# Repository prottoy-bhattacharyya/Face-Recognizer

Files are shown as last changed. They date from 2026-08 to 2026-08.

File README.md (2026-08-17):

# Smart Room & Gate Access Control System

A face-recognition-based IoT access control and room automation system. The project combines an ESP32-CAM, two ESP8266 microcontrollers, and a Django backend running YOLOv8 + DeepFace to let users unlock a gate with their face (or a PIN fallback) and remotely control room fan and lighting — with admin-only controls over face enrollment and the gate password.






---

## Table of Contents

- [Overview](#overview)
- [System Architecture](#system-architecture)
- [Hardware Components](#hardware-components)
- [Features](#features)
- [User Roles](#user-roles)
- [Getting Started](#getting-started)
  - [Backend (Django) Setup](#backend-django-setup)
  - [Firmware Setup](#firmware-setup)
- [API Reference](#api-reference)
  - [Django Server Endpoints](#django-server-endpoints)
  - [ESP8266 #2 (Room Automation) Endpoints](#esp8266-2-room-automation-endpoints)
- [Access Control Flow](#access-control-flow)
- [Web & Android Apps](#web--android-apps)
- [Roadmap / Known Limitations](#roadmap--known-limitations)
- [License](#license)

---

## Overview

The system is built around three microcontroller-class devices and a central Django server:

- **ESP32-CAM** — streams live video used for face capture.
- **ESP8266 #1 (Access Control Unit)** — keypad + OLED display; triggers face verification and handles PIN fallback.
- **ESP8266 #2 (Room Automation Unit)** — drives the gate servo, fan servo, room LEDs, and reads a DHT11 temperature/humidity sensor.
- **Django backend** — performs face detection (YOLOv8) and face matching (DeepFace), manages user accounts, and exposes a REST API consumed by both microcontrollers and the web/Android apps.

## System Architecture

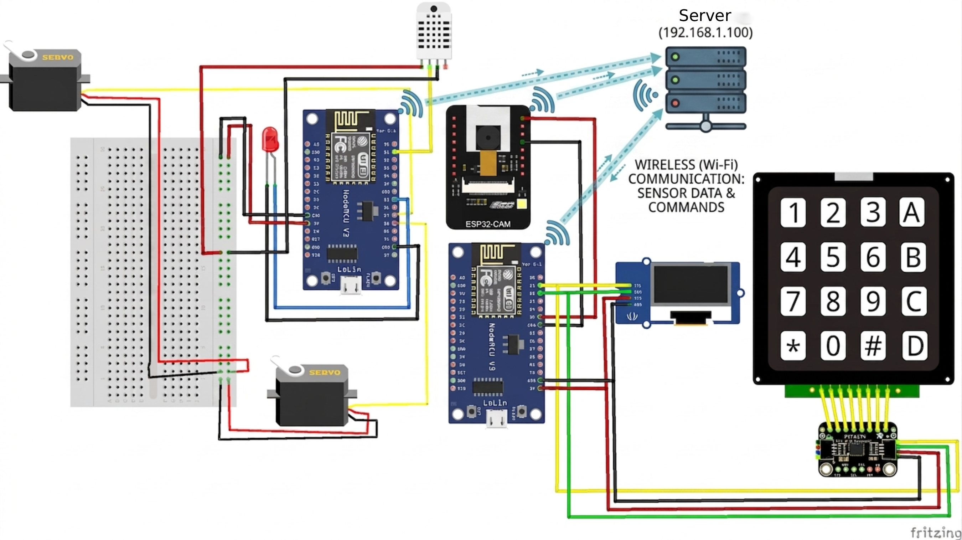
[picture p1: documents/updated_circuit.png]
Circuit Diagram


- **Security loop:** camera → server → ESP8266 #1 → ESP8266 #2, gated by face or PIN verification.
- **Convenience loop:** web/Android app talks directly to ESP8266 #2 for fan and light control, bypassing the server.

## Hardware Components

| Component | Role |
| --- | --- |
| ESP32-CAM | Captures and streams live video frames for face detection and enrollment |
| ESP8266 #1 (Access Control)  | Keypad + OLED interface; authenticates with Django, triggers face verification, handles PIN fallback |
| ESP8266 #2 (Room Automation) | Local web server exposing gate, fan, light, and sensor control endpoints |
| 4x4 Matrix Keypad + PCF8574  | Manual PIN entry via I2C GPIO expansion |
| SSD1306 OLED Display | Shows system status, verification results, and PIN entry feedback |
| DHT11 Sensor | Room temperature and humidity for automatic fan control |
| Gate Servo | Actuates the gate lock/latch mechanism |
| Fan Servo | Drives the fan on/off actuator |
| Blue / Yellow LEDs | Room light ON/OFF indicators |

## Features

- 🎯 **Face-recognition gate entry** using YOLOv8 for detection and DeepFace for matching
- 🔢 **PIN fallback** via a physical keypad if face verification fails
- 🌡️ **Automatic fan control** based on a configurable temperature threshold (with hysteresis)
- 💡 **Remote light and fan control** from a web dashboard and Android app
- 🚪 **Auto-closing gate** (5-second timer) with no separate close request needed
- 🔐 **Role-based access** — only the admin account can enroll/delete faces or change the gate password
- 📶 **Session-based authentication** shared between the Django server and both ESP8266 units

## User Roles

| Capability | Admin Account |  Regular User |
| --- | :---: | :---: |
| Open gate via face recognition | ✅ | ✅ |
| Open gate via keypad PIN | ✅ | ✅ (shared PIN) |
| Control fan / light (web & Android) | ✅ | ✅ |
| Enroll a new face | ✅ | ❌ |
| Delete a face / reset database | ✅ | ❌ |
| Update the gate password | ✅ | ❌ |

## Getting Started

### Backend (Django) Setup

**Requirements:** Python 3.9+, MySQL/MariaDB (or your configured DB), a webcam-compatible MJPEG stream URL.

```bash
# Clone the repository
git clone https://github.com/<your-username>/<your-repo>.git
cd <your-repo>/server

# install uv
pip install uv
```

Configure your database and camera settings (e.g. in `settings.py` or a `.env` file):

```python
CAMERA_URL = "http://<esp32-cam-ip>"
CONTROL_SERVER_URL = "http://<esp8266-2-ip>/"
```

Run database migrations and start the server:

```bash
python -m uv run manage.py migrate
python -m uv run manage.py runserver 0.0.0.0:8000
```

The YOLOv8 face model (`yolov8n-face.pt`) is loaded automatically from the `models/` directory on first run.

### Firmware Setup

Both ESP8266 sketches are written for the **Arduino IDE** (or PlatformIO) targeting the ESP8266 board package.

1. Install required libraries: `ESP8266WiFi`, `ESP8266HTTPClient`, `ESP8266WebServer`, `ArduinoJson`, `Adafruit_GFX`, `Adafruit_SSD1306`, `I2CKeyPad`, `Servo`, `DHT sensor library`.
2. Update the Wi-Fi credentials and server URLs at the top of each `.ino` file:
   ```cpp
   const char* ssid = "<your-wifi-ssid>";
   const char* password = "<your-wifi-password>";
   String server_url = "http://<django-server-ip>:8000/";
   String second_esp_url = "http://<esp8266-2-ip>/";
   ```
3. Flash `esp8266_access_control` to ESP8266 #1 and `esp8266_room_automation` to ESP8266 #2.
4. Flash the standard ESP32-CAM web server firmware (e.g. `CameraWebServer` example) to the ESP32-CAM, pointed at the same network.

## API Reference

### Django Server Endpoints

| Endpoint | Method | Access | Description |
| --- | --- | --- | --- |
| `/` | GET | Authenticated | Main dashboard |
| `/controls/` | GET | Authenticated | Room controls page (fan/light/gate) |
| `/login/` | GET, POST | Public | Authenticate and start a session |
| `/signup/` | GET, POST | Public | Register a new user account |
| `/logout/` | GET | Authenticated | Flush the current session |
| `/get_updated_password/?username={username}` | GET | Authenticated | Retrieve the current gate PIN |
| `/update_password/` | POST | Admin only | Update the gate password |
| `/faces/{name}/` | POST | Admin only | Capture a frame and enroll a new face |
| `/faces/{name}/` | DELETE | Admin only | Delete a specific user's face data |
| `/faces/` | DELETE | Admin only | Delete **all** enrolled faces |
| `/verify/?threshold={value}` | GET | Authenticated | Capture a frame and match it against enrolled faces |

### ESP8266 #2 (Room Automation) Endpoints

| Endpoint | Method | Description |
| --- | --- | --- |
| `/gate_open` | GET | Opens the gate; auto-closes after 5 seconds |
| `/mode?state={auto\|manual}` | GET | Switches fan control mode |
| `/turn_on_light` | GET | Turns the room light ON |
| `/turn_off_light` | GET | Turns the room light OFF |
| `/fan?state={on\|off}` | GET | Manually sets the fan state |
| `/sensors` | GET | Returns current temperature and humidity |
| `/status` | GET | Returns full system status (mode, light, fan, gate, sensor readings) |

## Access Control Flow

1. ESP8266 #1 logs in to Django on boot and syncs the current gate PIN.
2. Pressing **A** on the keypad triggers `GET /verify/`. On a `"success"` response, ESP8266 #1 calls ESP8266 #2's `/gate_open`.
3. If face verification fails, the user can enter a PIN on the keypad; pressing **#** checks it against the synced PIN and opens the gate on a match.
4. The gate auto-closes 5 seconds after opening — no separate close command is required.

## Web & Android Apps

- **Fan / light / gate control** — sent directly to ESP8266 #2, available to any authenticated user.
- **Face enrollment, face deletion, and gate password updates** — routed through the Django server and restricted to the `admin` account.
- **Face-based gate entry** — available to any enrolled user via `/verify/`.

## Roadmap / Known Limitations

- [ ] Encrypt stored gate passwords instead of plaintext comparison
- [ ] Move hardcoded Wi-Fi/admin credentials in firmware to a config file or provisioning flow
- [ ] Add HTTPS/session hardening between ESP8266 units and the Django server
- [ ] Wire automatic light/fan activation into the gate-open sequence (currently commented out)

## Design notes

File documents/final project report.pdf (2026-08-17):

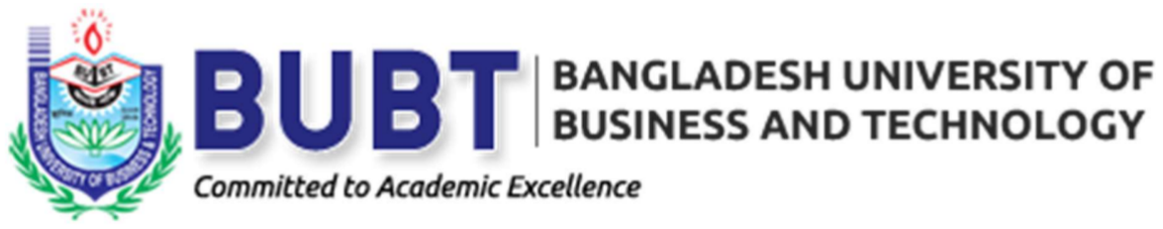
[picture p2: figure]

### BANGLADESH UNIVERSITY OF BUSINESS AND TECHNOLOGY

Department of Computer Science and Engineering

## Design and Implementation of an Edge-IoT and Centralized AI Facial Recognition System for Smart Access Control and Automation

Submitted By

Name | ID

Prottoy Vhattacharyya 20234103430

Chinmoy Roy Dipto | 20234103449
Arifa Islam | 20234103205
Suraiya Rahman Mitu | 20234103215

Submitted To

Ankan Saha
Lecturer
Department of CSE
Bangladesh University of
Business and Technology (BUBT)

Date: August 17, 2026

Smart Room & Gate Access Control System | Project Report

Abstract

This report documents the design and implementation of an IoT-based smart room and gate access control system that combines face recognition, keypad PIN fallback, and remote environmental control. The system integrates an ESP32-CAM for video capture, two ESP8266 microcontrollers for access control and room automation respectively, and a Django backend that performs face detection (YOLOv8) and face recognition (DeepFace). Authorized users can unlock the gate via face verification or a PIN code and control room fan and lighting through companion web and Android applications, while administrative operations such as face enrollment, face deletion, and gate password management are restricted to an admin account.

### Contents

1 Introduction | 3
2 System Architecture | 3
3 Django Server API Endpoints | 6
4 ESP8266 #2 (Room Automation) API Endpoints | 7
5 Access Control Unit (ESP8266 #1) Behaviour | 8
6 Web and Android Applications | 9
7 Conclusion | 9

### 1 Introduction

The Smart Room & Gate Access Control System is an IoT security and automation solution designed to provide contactless, face-recognition-based gate access alongside remote control of room appliances (fan and light). The system is built around three microcontroller-class devices and a central Django server:

- An ESP32-CAM module that streams live video for face capture.
- A primary ESP8266 (Access Control Unit) equipped with a keypad, OLED display, and I/O expander, responsible for triggering face verification and handling PIN-based fallback authentication.
- A secondary ESP8266 (Room Automation Unit) that drives the gate servo, fan servo, room LEDs, and a DHT11 temperature/humidity sensor.
- A Django backend that performs face detection using YOLOv8, face matching using Deep-Face, manages user accounts, and exposes a REST API consumed by both microcontrollers as well as the web and Android applications.

The system supports two classes of users: an admin account with full control over the face database and gate password, and regular users who may open the gate via face verification and operate the fan and light, but cannot enroll or delete faces or change the gate password.

### 2 System Architecture

### 2.1 Circuit Diagram

Figure 1 shows the complete hardware wiring of the system, including both ESP8266 modules, the ESP32-CAM, the DHT11 sensor, gate and fan servos, the 4x4 matrix keypad connected via a PCF8574 I2C GPIO expander, and the OLED status display.

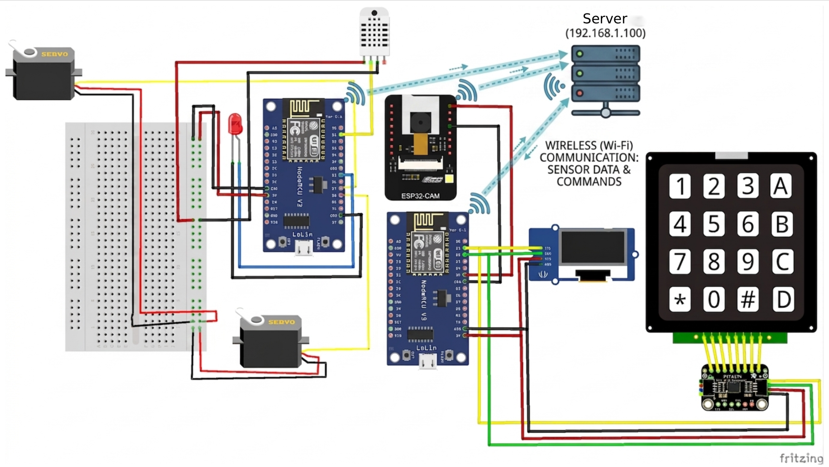
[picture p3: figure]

Figure 1: Complete circuit diagram of the Smart Room & Gate Access Control System, showing the two ESP8266 modules, ESP32-CAM, DHT11 sensor, gate/fan servos, OLED display, and I2C keypad with PCF8574 expander (Fritzing).

### 2.2 Hardware Components

Component | Role
ESP32-CAM | Captures and streams live video frames used for face de-
tection and enrollment.

ESP8266 #1 (Access Control) Runs the keypad interface and OLED display; authenticates with Django, triggers face verification, handles PIN fallback, and signals ESP8266 #2 to open the gate.

ESP8266 #2 (Room Automation)

Hosts a local web server exposing gate, fan, light, and sensor control endpoints; runs the auto temperaturecontrolled fan logic.

4x4 | Matrix | Keypad | +
PCF8574

Provides manual PIN entry via I2C GPIO expansion.

SSD1306 OLED Display | Shows system status, verification results, and PIN entry
feedback.
DHT11 Sensor | Measures room temperature and humidity for automatic
fan control.
Gate Servo | Physically actuates the gate lock/latch mechanism.
Fan Servo | Drives the fan speed/on-off actuator.
LEDs | Represent the room light ON/OFF states.

### 2.3 Communication Overview

Both ESP8266 units communicate with the Django server and with each other over the local Wi-Fi network:

- ESP8266 #1 ↔ Django Server: Logs in with admin credentials to obtain a session cookie, periodically syncs the gate PIN from the server, calls the /verify/ endpoint to check a captured face, and calls /faces/{name}/ to enroll new users.
- ESP8266 #1 → ESP8266 #2: On successful face verification (or correct PIN entry), ESP8266 #1 sends an HTTP GET request to ESP8266 #2’s /gate_open endpoint to physically open the gate.
- ESP8266 #2 ↔ Django Server / Web & Android Apps: Exposes its own local REST API (fan, light, gate, sensors) which is consumed directly by the web dashboard and Android application for real-time room control, independent of the face-recognition flow.
- ESP32-CAM → Django Server: Streams video continuously; the Django server pulls a frame from this stream whenever a face capture is requested (enrollment or verification).

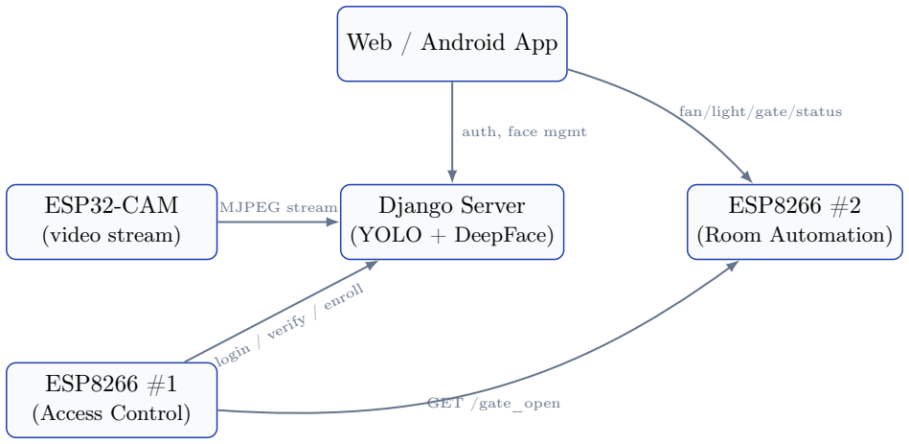
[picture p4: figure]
ESP32-CAM; (video stream); Django Server; (YOLO + DeepFace); Web / Android App; ESP8266 #2; (Room Automation); ESP8266 #1; (Access Control); MJPEG stream; login / verify / enroll; GET /gate_open; auth, face mgmt; fan/light/gate/status

Figure 2: High-level communication flow between devices, the Django server, and client applications.

### 2.4 Explanation of Figure 2

Figure 2 is a simplified block diagram showing how the five main components of the system exchange data over the local network. Each box represents a device or application, and each arrow represents a distinct HTTP communication path.

### 2.4.1 Nodes

- ESP32-CAM — the camera unit that continuously streams video.
- Django Server — the backend running YOLOv8 (face detection) and DeepFace (face matching).
- ESP8266 #1 — the Access Control Unit (keypad and OLED display).
- ESP8266 #2 — the Room Automation Unit (fan, light, and gate).
- Web / Android App — the client applications used by end users.

### 2.4.2 Communication Paths

1. ESP32-CAM → Django Server (MJPEG stream): the camera continuously streams video to the server. The server pulls a single frame from this stream whenever it needs to detect or match a face, i.e. during a call to /verify/ or /faces/{name}/.
2. ESP8266 #1 → Django Server (login / verify / enroll): the access-control unit logs in to obtain a session cookie, then calls /verify/ when a user presses the A key on the keypad, and calls /faces/{name}/ when enrolling a new user.
3. ESP8266 #1 → ESP8266 #2 (GET /gate_open): this is the key handoff in the security flow. Once ESP8266 #1 receives a "success" response from /verify/, or the user enters a correct PIN, it calls ESP8266 #2’s /gate_open endpoint directly to physically unlock the gate. This connection bypasses the Django server entirely — it is a direct device-to-device call over the local network.
4. Web/Android App → Django Server (auth, face mgmt): the client applications use the server for login/signup, and for admin-only operations such as enrolling or deleting faces and updating the gate password.
5. Web/Android App → ESP8266 #2 (fan/light/gate): for everyday room control, the applications talk directly to ESP8266 #2’s REST API rather than routing through Django,

since fan and light control does not require face recognition.

### 2.4.3 Key Takeaway

The diagram illustrates that the system is organized around two largely independent control loops:

- A security loop — camera → server → ESP8266 #1 → ESP8266 #2 — gated by face or PIN verification.
- A convenience loop — client apps talking directly to ESP8266 #2 for fan and light control.

The Django server sits in the middle primarily as the authentication and face-recognition authority, rather than as a pass-through relay for every hardware command.

### 3 Django Server API Endpoints

The Django backend exposes the following REST endpoints. Face detection is performed with a fine-tuned YOLOv8 face model, and recognition against enrolled users is performed with DeepFace over a per-user image database.

GET /
Renders the main dashboard (index.html) with the camera stream URL and control server URL. Requires an active session; redirects to /login/ otherwise.

GET /controls/
Renders the room controls page (controls.html) used to operate the fan, light, and gate via ESP8266 #2.

GET / POST /login/

Authenticates a user against the users table and starts a session. On POST with valid credentials, redirects to /; on failure, re-renders the login page with an error message.

GET / POST /signup/

Registers a new user account. Rejects duplicate usernames; on success, logs the new user in and redirects to /.

GET /logout/
Flushes the current session and redirects to the login page.

GET /get_updated_password/?username={username}
Returns the current gate PIN (gate_password) stored for the given user. Used by ESP8266 #1 to periodically sync the PIN used for keypad fallback authentication.

POST /update_password/
Admin only. Updates the gate password for the logged-in admin session. Requires the request body field new_password. Returns 401 if the session is missing or does not belong to the admin account.

POST /faces/{name}/
Admin only. Captures a frame from the camera stream, detects the largest/most confident face with YOLOv8, and enrolls it under the given username. Clears the cached DeepFace embeddings so the new face is included in future verification.

DELETE /faces/{name}/
Admin only. Deletes the enrolled face data for a specific user and clears the DeepFace cache.

DELETE /faces/
Admin only. Deletes all enrolled faces and resets the face database directory.

GET /verify/?threshold={value}
Captures a frame, detects a face, and matches it against all enrolled users using DeepFace. Returns the matched username and a confidence score if the match distance is within the given threshold (default 0.5); otherwise returns a 401 failure response. This endpoint is available to any authenticated user, not just the admin, since any enrolled user may open the gate with their own face.

### 3.1 Access Control Summary

Endpoint | Method | Access Level
/faces/{name}/ | POST, DELETE | Admin only
/faces/ | DELETE | Admin only
/update_password/ | POST | Admin only
/verify/ | GET | Any authenticated user
/get_updated_password/ | GET | Any authenticated user
/, /controls/ | GET | Any authenticated user
/login/, /signup/, /logout/ | GET/POST | Public

### 4 ESP8266 #2 (Room Automation) API Endpoints

ESP8266 #2 hosts a lightweight HTTP server on port 80 that drives the gate, fan, and light hardware, and reports live sensor readings. All endpoints return a JSON status object produced

by getSystemStatusJson().

GET /gate_open
Opens the gate by driving the door servo to 180°. The gate automatically closes after 5 seconds via a non-blocking timer (checkGateAutoClose()), without requiring a separate close request.

GET /mode?state={auto|manual}
Switches the system between AUTO mode (fan is driven automatically based on the temperature threshold) and MANUAL mode (fan is controlled only by explicit requests). Returns 400 if the state parameter is missing or invalid.

GET /turn_on_light
Turns the room light ON (drives the blue LED high, yellow LED low).

GET /turn_off_light
Turns the room light OFF (drives the blue LED low, yellow LED high).

GET /fan?state={on|off}
Manually sets the fan servo state. Returns 400 for a missing or invalid state parameter.

GET /sensors
Reads the DHT11 sensor and returns the current temperature and humidity. Returns 500 if the sensor read fails.

GET /status
Returns the full system status: current mode, light status, fan status, gate status, configured temperature threshold, and the last known temperature/humidity readings. Includes a permissive CORS header so it can be polled directly from the web dashboard.

### 4.1 Automatic Temperature Control

When the system is in AUTO mode, checkTemperatureAutoControl() runs every 3 seconds: the fan is switched ON once the temperature reaches the threshold (30◦C) and switched OFF once it drops at least 1

◦C below the threshold, providing simple hysteresis to avoid rapid on/off cycling.

### 5 Access Control Unit (ESP8266 #1) Behaviour

ESP8266 #1 mediates between the physical keypad/OLED interface and the Django server:

1. On boot, it connects to Wi-Fi, logs in to Django with the admin credentials to obtain a session cookie, and syncs the current gate PIN via /get_updated_password/.

2. Pressing A on the keypad triggers verify_face(), which calls GET /verify/. If the response status is "success", the unit calls ESP8266 #2’s /gate_open endpoint to unlock the gate.
3. If face verification fails, the user can fall back to PIN entry: digits are collected on the keypad and, on pressing #, compared against the locally cached PIN (refreshed from the server on every attempt). A correct PIN also triggers /gate_open on ESP8266 #2.
4. Pressing C clears the currently entered PIN, and the OLED display shows masked input (*) as digits are typed.

### 6 Web and Android Applications

In addition to the physical keypad and face-recognition flow, the system is accompanied by
a web dashboard and a companion Android application. Both clients talk to the same backend surfaces described above:
- Room controls (fan, light, gate) are sent directly to ESP8266 #2’s REST API (/turn_on_light, /turn_off_light, /fan, /gate_open, /status) and are available to any authenticated user, not just the admin.
- Face management (enroll, delete) and the gate password update are routed through the Django server’s /faces/{name}/, /faces/, and /update_password/ endpoints, which are restricted to the admin account at the server level.
- Face-based gate entry is available to every enrolled user through /verify/ — any registered face that matches within the configured threshold can open the gate, regardless of whether that account is the admin.

### 6.1 User Roles Summary

Capability | Admin Account | Regular User
Open gate via face recognition | Yes | Yes
Open gate via keypad PIN | Yes | Yes (shared PIN)
Control fan / light (web & Android) | Yes | Yes
Enroll a new face | Yes | No
Delete a face / reset database | Yes | No
Update the gate pass- word | Yes | No

### 7 Conclusion

The Smart Room & Gate Access Control System demonstrates a practical integration of computervision-based access control with everyday IoT room automation. By splitting responsibilities across a dedicated access-control ESP8266, a room-automation ESP8266, an ESP32-CAM, and a Django server that performs the heavier face detection and recognition workload, the system keeps each microcontroller’s firmware simple while centralizing security-sensitive operations like face enrollment, deletion, and gate password changes behind admin-only server-side checks. The accompanying web and Android applications extend this same access model to everyday users, allowing convenient control of the fan and light while keeping database-altering operations restricted to the administrator.

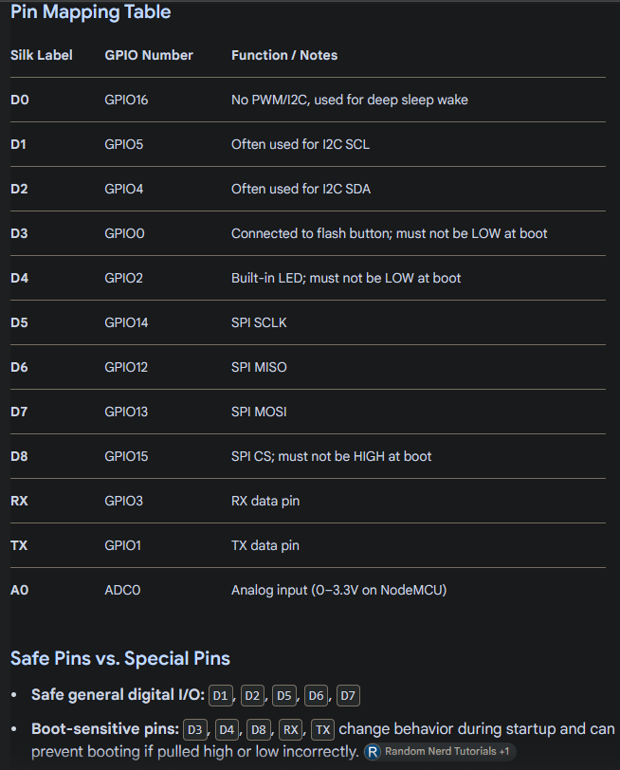
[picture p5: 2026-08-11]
documents/pin map.png

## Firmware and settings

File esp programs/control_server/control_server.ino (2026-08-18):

#include <ESP8266WiFi.h>
#include <ESP8266WebServer.h>
#include <Servo.h>
#include <DHT.h>

const char *ssid = "IoT Lab";
const char *password = "bubt1234";
// const char* ssid = "Bachelor Family 2.4G";
// const char* password = "passwordnai";

ESP8266WebServer server(80);

#define BLUE_LED_PIN 14  // D5
#define YLW_LED_PIN 12   // D6
#define DHT_PIN 4        // D2
#define DHTTYPE DHT11
#define DOOR_SERVO_PIN D7
#define FAN_SERVO_PIN D8

DHT dht(DHT_PIN, DHTTYPE);

Servo door_servo;
Servo fan_servo;

// Global State Variables
bool isLightOn = false;
bool isFanOn = false;
bool isAutoMode = false; // Default to MANUAL mode

// Non-blocking Gate Control Variables
bool isGateOpen = false;
unsigned long gateOpenStartTime = 0;
const unsigned long GATE_OPEN_DURATION = 5000; // 5 seconds open time

// Auto Temperature Control Settings
const float TEMP_THRESHOLD = 30.0;
unsigned long lastSensorReadTime = 0;
const unsigned long SENSOR_INTERVAL = 3000;
float currentTemp = 0.0;
float currentHum = 0.0;

void setLightState(bool turnOn) {
  if (turnOn) {
    digitalWrite(BLUE_LED_PIN, HIGH);
    digitalWrite(YLW_LED_PIN, LOW);
    isLightOn = true;
  } else {
    digitalWrite(BLUE_LED_PIN, LOW);
    digitalWrite(YLW_LED_PIN, HIGH);
    isLightOn = false;
  }
}

void setFanState(bool turnOn) {
  if (turnOn) {
    fan_servo.write(0);
    isFanOn = true;
  } else {
    fan_servo.write(90);
    isFanOn = false;
  }
}

void setGateState(bool openState) {
  if (openState) {
    door_servo.write(180);
    isGateOpen = true;
    gateOpenStartTime = millis();
  } else {
    door_servo.write(0);
    isGateOpen = false;
  }
}

String getSystemStatusJson(float temp = -999.0, float hum = -999.0) {
  bool lightState = digitalRead(BLUE_LED_PIN);
  String json = "{";
  json += "\"mode\":\"" + String(isAutoMode ? "AUTO" : "MANUAL") + "\",";
  json += "\"light_status\":\"" + String(lightState ? "ON" : "OFF") + "\",";
  json += "\"fan_status\":\"" + String(isFanOn ? "ON" : "OFF") + "\",";
  json += "\"gate_status\":\"" + String(isGateOpen ? "OPEN" : "CLOSED") + "\",";
  json += "\"temp_threshold\":" + String(TEMP_THRESHOLD);
  
  if (temp != -999.0 && hum != -999.0) {
    json += ",\"temperature\":" + String(temp);
    json += ",\"humidity\":" + String(hum);
  }
  else{
    json += ",\"temperature\": \"NULL\"";
    json += ",\"humidity\": \"Null\"";
  }
  
  json += "}";
  return json;
}

void checkTemperatureAutoControl() {
  // Only evaluate auto temperature logic if system is in AUTO mode
  if (!isAutoMode) return;

  float temp = dht.readTemperature();
  float hum = dht.readHumidity();

  if (isnan(temp) || isnan(hum)) {
    Serial.println("Warning: Failed to read from DHT sensor!");
    return;
  }

  currentTemp = temp;
  currentHum = hum;

  if (currentTemp >= TEMP_THRESHOLD && !isFanOn) {
    Serial.println("[AUTO CONTROL] Temp >= Threshold. Fan ON.");
    setFanState(true);
  } else if (currentTemp < (TEMP_THRESHOLD - 1.0) && isFanOn) {
    Serial.println("[AUTO CONTROL] Temp cooled. Fan OFF.");
    setFanState(false);
  }
}

// Non-blocking Gate Auto-Close Timer
void checkGateAutoClose() {
  if (isGateOpen && (millis() - gateOpenStartTime >= GATE_OPEN_DURATION)) {
    Serial.println("[AUTO GATE] Closing gate...");
    setGateState(false);
  }
}

void handleGateOpen() {
  Serial.println("Received command: Open Gate");
  
  // Open gate and turn on fan + light
  setGateState(true);
  // setLightState(true);
  // setFanState(true);

  server.send(200, "application/json", getSystemStatusJson(currentTemp, currentHum));
}

void handleModeControl() {
  if (server.hasArg("state") || server.hasArg("mode")) {
    String modeParam = server.hasArg("state") ? server.arg("state") : server.arg("mode");
    modeParam.toLowerCase();

    if (modeParam == "auto") {
      isAutoMode = true;
      Serial.println("[MODE] System set to AUTO");
      server.send(200, "application/json", getSystemStatusJson(currentTemp, currentHum));
    } else if (modeParam == "manual") {
      isAutoMode = false;
      Serial.println("[MODE] System set to MANUAL");
      server.send(200, "application/json", getSystemStatusJson(currentTemp, currentHum));
    } else {
      server.send(400, "application/json", "{\"status\":\"error\",\"message\":\"Invalid mode. Use 'auto' or 'manual'.\"}");
    }
  } else {
    server.send(400, "application/json", "{\"status\":\"error\",\"message\":\"Missing 'state' query parameter.\"}");
  }
}

void handleTurnOnLight() {
  setLightState(true);
  server.send(200, "application/json", getSystemStatusJson(currentTemp, currentHum));
}

void handleTurnOffLight() {
  setLightState(false);
  server.send(200, "application/json", getSystemStatusJson(currentTemp, currentHum));
}

void handleFanControl() {
  if (server.hasArg("state")) {
    String state = server.arg("state");
    if (state == "on") {
      setFanState(true);
      server.send(200, "application/json", getSystemStatusJson(currentTemp, currentHum));
    } else if (state == "off") {
      setFanState(false);
      server.send(200, "application/json", getSystemStatusJson(currentTemp, currentHum));
    } else {
      server.send(400, "application/json", "{\"status\":\"error\",\"message\":\"Invalid state parameter.\"}");
    }
  } else {
    server.send(400, "application/json", "{\"status\":\"error\",\"message\":\"Missing 'state' query parameter.\"}");
  }
}

void handleSensorData() {
  float temp = dht.readTemperature();
  float hum = dht.readHumidity();

  if (isnan(temp) || isnan(hum)) {
    server.send(500, "application/json", "{\"status\":\"error\",\"message\":\"Failed to read from DHT sensor\"}");
    return;
  }

  currentTemp = temp;
  currentHum = hum;
  server.send(200, "application/json", getSystemStatusJson(currentTemp, currentHum));
}

void handleGetStatus() {
  server.sendHeader("Access-Control-Allow-Origin", "*");
  server.send(200, "application/json", getSystemStatusJson(currentTemp, currentHum));
}

void setup() {
  Serial.begin(115200);

  pinMode(BLUE_LED_PIN, OUTPUT);
  pinMode(YLW_LED_PIN, OUTPUT);
  
  door_servo.attach(DOOR_SERVO_PIN);
  fan_servo.attach(FAN_SERVO_PIN);
  
  // Explicitly keep appliances OFF on startup
  setGateState(false);
  setFanState(false);
  setLightState(false);

  dht.begin();

  WiFi.begin(ssid, password);
  Serial.print("Connecting to WiFi");
  while (WiFi.status() != WL_CONNECTED) {
    delay(500);
    Serial.print(".");
  }
  Serial.println("\nSecond ESP8266 Connected!");
  Serial.print("IP Address: ");
  Serial.println(WiFi.localIP());

  // Web API Routes
  server.on("/gate_open", handleGateOpen);
  server.on("/mode", handleModeControl);
  server.on("/turn_on_light", handleTurnOnLight);
  server.on("/turn_off_light", handleTurnOffLight);
  server.on("/fan", handleFanControl);
  server.on("/sensors", handleSensorData);
  server.on("/status", handleGetStatus);

  server.begin();
  Serial.println("HTTP server started");
}

void loop() {
  server.handleClient();

  checkGateAutoClose();

  if (millis() - lastSensorReadTime >= SENSOR_INTERVAL) {
    lastSensorReadTime = millis();
    checkTemperatureAutoControl();
  }
}

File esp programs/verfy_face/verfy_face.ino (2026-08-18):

#include <ESP8266WiFi.h>
#include <ESP8266HTTPClient.h>
#include <WiFiClient.h>
#include "ArduinoJson.h"

#include <SPI.h>
#include <Wire.h>
#include <Adafruit_GFX.h>
#include <Adafruit_SSD1306.h>
#include <I2CKeyPad.h>

#define KEYPAD_ADDRESS 0x20
#define LED_ADDRESSS 0x3C
#define SCREEN_WIDTH 128
#define SCREEN_HEIGHT 32
#define OLED_RESET    -1

char keymap[19] = "123A456B789C*0#DNF";

I2CKeyPad keypad(KEYPAD_ADDRESS);
Adafruit_SSD1306 display(SCREEN_WIDTH, SCREEN_HEIGHT, &Wire, OLED_RESET);

const char *ssid = "IoT Lab";
const char *password = "bubt1234";  
// const char* ssid = "Bachelor Family 2.4G";
// const char* password = "passwordnai";

String CORRECT_PIN = "1234";
String inputPassword = "";
String sessionCookie = ""; // Stores Django sessionid cookie

String server_url = "http://192.168.68.131:8000/";
String second_esp_url = "http://192.168.68.135/";

WiFiClient client;
HTTPClient http;

void triggerSecondESP() {
  if (WiFi.status() == WL_CONNECTED) {
    HTTPClient httpSecond;
    httpSecond.begin(client, second_esp_url + "gate_open");
    int httpCode = httpSecond.GET();
    if (httpCode > 0) {
      Serial.println("Second ESP8266 responded: " + String(httpCode));
    } else {
      Serial.println("Error communicating with Second ESP: " + String(httpCode));
    }
    httpSecond.end();
  }
}

void showText(String line1, String line2 = "") {
  display.clearDisplay();
  display.setTextSize(1);
  display.setTextColor(SSD1306_WHITE);
  
  display.setCursor(0, 0);
  display.println(line1);
  
  if (line2.length() > 0) {
    display.setCursor(0, 16);
    display.println(line2);
  }
  
  display.display();
}

bool checkRequest(String action, String payload) {
  JsonDocument doc;
  DeserializationError error = deserializeJson(doc, payload);

  if (error) {
    Serial.print("JSON parsing failed: ");
    Serial.println(error.c_str());
    showText(action + " Failed", "JSON Parse Error");
    return false;
  }

  String status = doc["status"].as<String>();

  if (status == "success") {
    String message = "";
    if (doc.containsKey("name")) {
      message = doc["name"].as<String>();
    } else if (doc.containsKey("message")) {
      message = doc["message"].as<String>();
    } else {
      message = "Success";
    }

    Serial.println("[" + action + "] OK: " + message);
    showText(action + ": OK", message);
    return true;
  }

  if (status == "failed") {
    String errorMsg = "Unknown error";
    if (doc.containsKey("description")) {
      errorMsg = doc["description"].as<String>();
    }

    Serial.println("[" + action + "] Error: " + errorMsg);
    showText(action + ": FAILED", errorMsg);
    return false;
  }

  return false;
}

void login() {
  if (WiFi.status() == WL_CONNECTED) {
    http.begin(client, server_url + "login/");
    http.addHeader("Content-Type", "application/json");

    // Tell HTTPClient to collect Set-Cookie from server headers
    const char* headerKeys[] = {"Set-Cookie"};
    http.collectHeaders(headerKeys, 1);

    String loginPayload = "{\"username\": \"admin\", \"password\": \"admin123\"}";
    int httpCode = http.POST(loginPayload);

    if (httpCode > 0) {
      if (http.hasHeader("Set-Cookie")) {
        sessionCookie = http.header("Set-Cookie");
        Serial.println("Session cookie saved successfully!");
      }
      Serial.println("Login Response Code: " + String(httpCode));
    } else {
      Serial.println("Login failed: " + http.errorToString(httpCode));
    }
    http.end();
  }
}

void syncPassword() {
  if (WiFi.status() == WL_CONNECTED) {
    // Define target username
    String targetUser = "admin"; 

    // Append query parameter to the URL
    String url = server_url + "get_updated_password/?username=" + targetUser;
    http.begin(client, url);

    // Pass session cookie if Django session authentication is required
    if (sessionCookie.length() > 0) {
      http.addHeader("Cookie", sessionCookie);
    }

    int httpCode = http.GET();

    if (httpCode == 200) {
      String payload = http.getString();
      JsonDocument doc;
      
      if (deserializeJson(doc, payload) == DeserializationError::Ok) {
        if (doc["status"] == "success") {
          CORRECT_PIN = doc["password"].as<String>();
          Serial.println("Updated local PIN to: " + CORRECT_PIN);
        }
      }
    } else {
      Serial.println("syncPassword HTTP Error Code: " + String(httpCode));
    }
    http.end();
  }
}

void enroll_face(String name) {
  showText("Enrolling...", name);
  http.begin(client, server_url + "faces/" + name + "/");
  http.addHeader("Content-Type", "application/json");
  if (sessionCookie.length() > 0) http.addHeader("Cookie", sessionCookie);

  int httpPostCode = http.POST("{}");
  if (httpPostCode > 0) {
    String payload = http.getString();
    checkRequest("Enroll", payload);
  } else {
    showText("Enroll Error", "HTTP Code: " + String(httpPostCode));
  }
  http.end();
}

void verify_face() {
  showText("Verifying...", "Scanning face");
  http.begin(client, server_url + "verify/");
  if (sessionCookie.length() > 0) http.addHeader("Cookie", sessionCookie);

  int httpGetCode = http.GET();
  if (httpGetCode > 0) {
    String payload = http.getString();
    if (checkRequest("Verify", payload)) {
      triggerSecondESP();
    }
  } else {
    showText("Verify Error", "HTTP Code: " + String(httpGetCode));
  }
  http.end();
}

void init_display() {
  if (!display.begin(SSD1306_SWITCHCAPVCC, LED_ADDRESSS)) {
    Serial.println(F("SSD1306 allocation failed"));
  }
  showText("System Init", "Starting...");
}

void init_keypad(){
  if (!keypad.begin()) {
    Serial.println("ERROR: Could not find I2C Keypad!");
    showText("Keypad Error", "Check 0x20");
  } else {
    Serial.println("SUCCESS: I2C Keypad found at " + String(KEYPAD_ADDRESS));
    keypad.loadKeyMap(keymap);
  }
}

void setup() {
  Serial.begin(115200);
  delay(500);

  WiFi.mode(WIFI_OFF);
  delay(100);

  Wire.begin(4, 5); // SDA = D2, SCL = D1
  Wire.setClock(100000);
  delay(100);

  Wire.beginTransmission(KEYPAD_ADDRESS);
  Wire.write(0xFF);
  Wire.endTransmission();
  delay(100);

  init_keypad();
  init_display();
  Wire.setClock(100000);

  delay(2000);

  WiFi.mode(WIFI_STA);
  showText("Connecting WiFi", ssid);
  WiFi.begin(ssid, password);

  while (WiFi.status() != WL_CONNECTED) {
    delay(500);
    Serial.print(".");
  }

  Serial.println("\nConnected to WiFi");
  Serial.println("IP: " + WiFi.localIP().toString());
  
  showText("WiFi Connected!", WiFi.localIP().toString());
  delay(1000);
  
  // Authenticate and fetch initial PIN state
  login();
  syncPassword();
  
  showText("Ready", "PIN or Press A");
}
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

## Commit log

2026-08-08 esp32 camera added
    [partitions.csv]
2026-08-10 LCD I2C added and response structure status, desc
2026-08-10 LCD I2C added and response structure status, desc, and some documents
2026-08-11 oled screen added
    [circut diagram.fzz]
2026-08-12 CHANGED TO mobile camera stream
2026-08-14 logout button, save login sessions
2026-08-15 circuit diagram updated
    [circut diagram.fzz]
2026-08-16 esp codes moved to esp programs folder
    [circut diagram.fzz, partitions.csv]
2026-08-17 updated readme and added updated circuit diagram

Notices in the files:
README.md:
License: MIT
